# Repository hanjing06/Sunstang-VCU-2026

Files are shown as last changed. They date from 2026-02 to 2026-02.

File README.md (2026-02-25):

# Sunstang VCU 2026  
Vehicle Control Unit PCB for Western Sunstang

---

## Overview

The **Sunstang VCU 2026** is a custom-designed Vehicle Control Unit PCB developed in **KiCad v6+**.

The board integrates driver inputs, high-voltage enable logic, lighting control, safety interlocks, and vehicle state management into a centralized low-voltage control system.

The system is built around the **STM32 Nucleo-F302R8** development board (ARM Cortex-M4, 3.3V logic).

This PCB acts as the hardware interface between the microcontroller and the vehicle’s 12V automotive systems.

---

## System Architecture

The VCU operates across two voltage domains:

| Domain | Voltage | Description |
|---|---|---|
| Logic Domain | 3.3V | STM32 microcontroller logic |
| Automotive LV Domain | 12V | Switches, contactors, lighting, HV control |

Signal conditioning ensures safe interfacing between 12V automotive signals and 3.3V MCU GPIO/ADC inputs.

---

### System Integration Diagram

The diagram below shows the high-level integration of:

- STM32 Nucleo-F302R8 (3.3V logic domain)
- 12V automotive domain subsystems
- Pre-charge & contactor control
- Driver interface
- Lighting systems
- BMS interface

<p align="center">
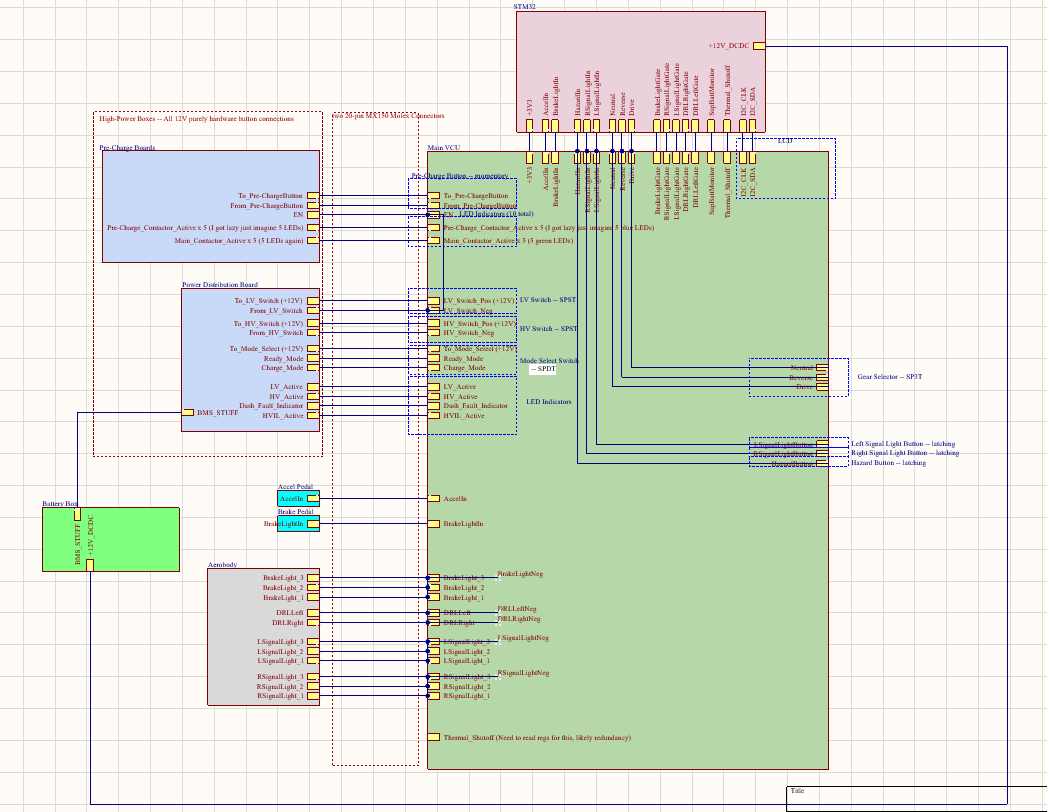
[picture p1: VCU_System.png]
  
</p>

---

## Microcontroller

**Board:** STM32 Nucleo-F302R8  
**Core:** ARM Cortex-M4  
**Logic Voltage:** 3.3V  

Primary functions:
- ADC acquisition (accelerator and brake pedals)
- Digital input processing (switches and selectors)
- Digital output control (contactors, LEDs, lighting)
- Vehicle state logic (ready mode, charge mode, HV enable)

Documentation:  
https://www.st.com/en/evaluation-tools/nucleo-f302r8.html

---

## Functional Responsibilities

The VCU manages the following subsystems:

### 1. Power & HV Control
- LV switch interface (12V)
- HV switch interface (12V)
- Pre-charge button input
- Pre-charge contactor feedback
- Main contactor feedback
- HV active indication
- BMS interface signals

### 2. Driver Inputs
- Accelerator pedal (ADC input)
- Brake pedal (ADC/digital input)
- Brake light trigger output

### 3. Mode Control
- Ready mode switch
- Charge mode switch
- Mode select (SPDT)
- Gear selector (SPST)

### 4. Lighting Control
- Brake lights
- Daytime running lights (DRL)
- Left turn signal
- Right turn signal
- Hazard (latching)
- Rear signal outputs

### 5. Safety Inputs
- HV active confirmation
- Thermal shutdown input (redundancy planned)
- Pre-charge verification before main contactor closure

---

## Startup Sequence (Simplified)

1. LV switch enabled  
2. HV switch engaged  
3. Pre-charge initiated  
4. Pre-charge confirmed  
5. Main contactor closed  
6. HV active verified  
7. Ready mode enabled  
8. Vehicle operational  

---

## Electrical Characteristics

| Parameter | Value |
|---|---|
| Automotive LV Input | 12V DC |
| MCU Logic Voltage | 3.3V |
| Microcontroller | STM32F302R8 |
| Design Tool | KiCad v6+ |

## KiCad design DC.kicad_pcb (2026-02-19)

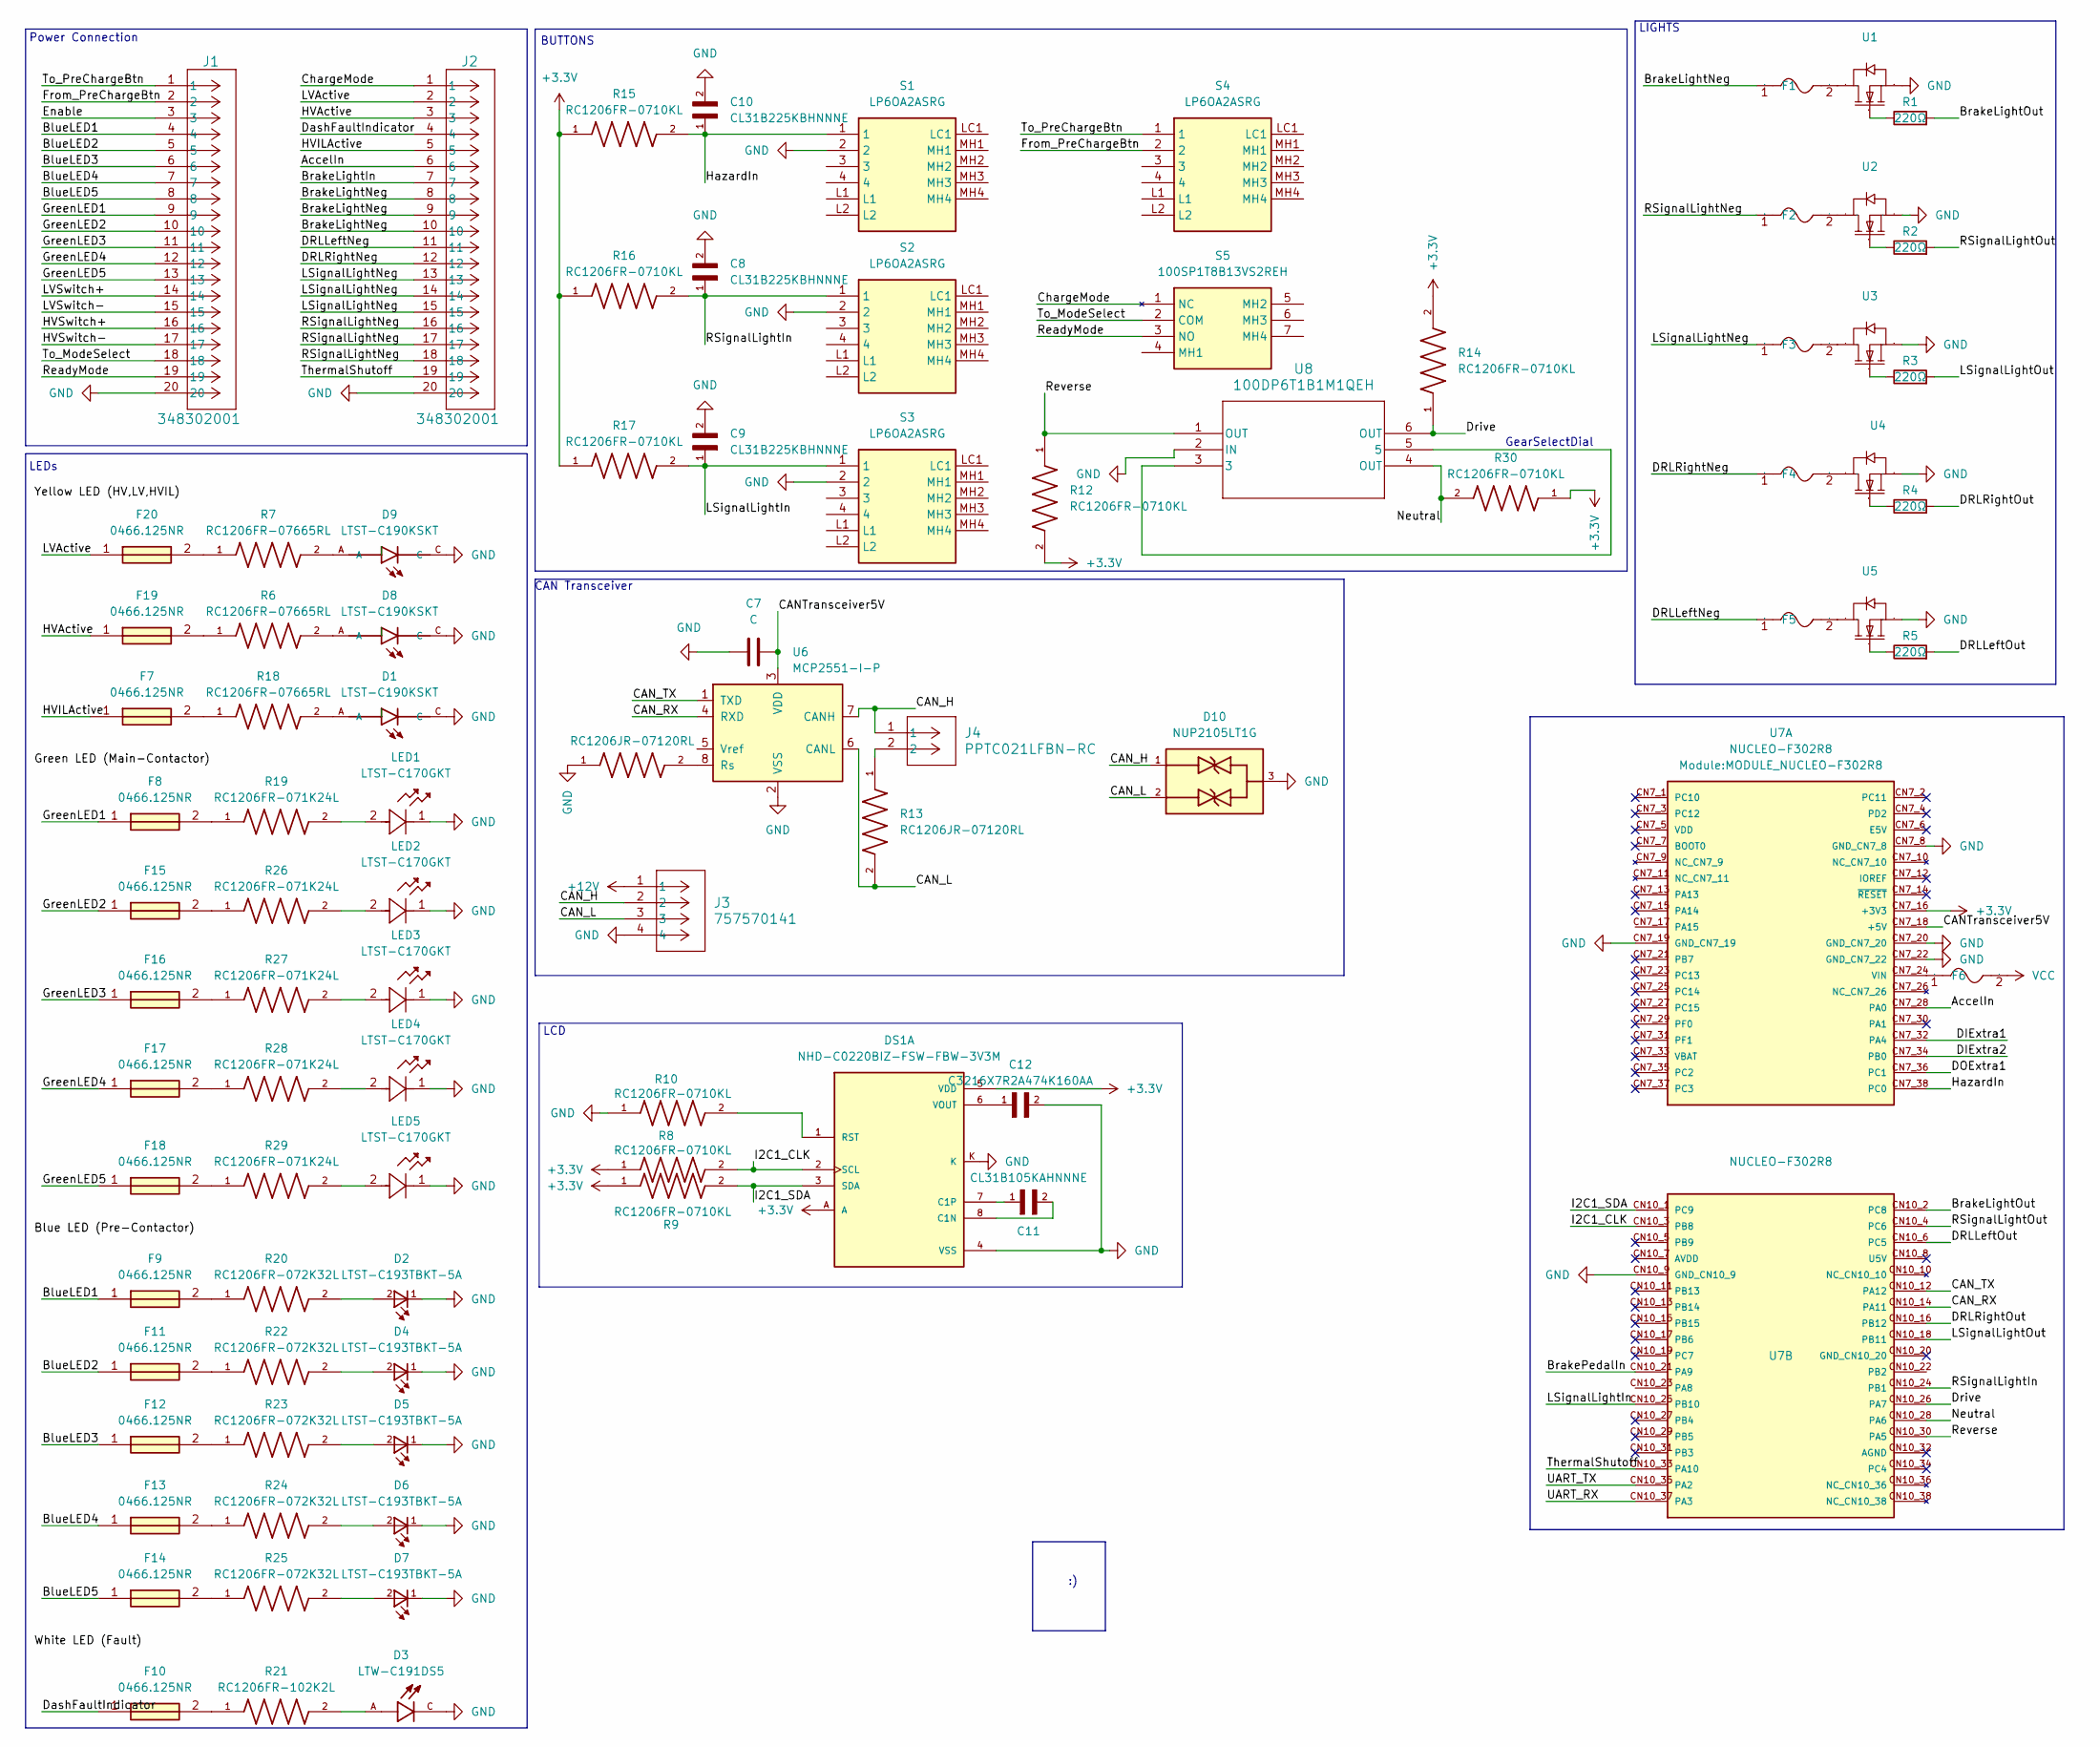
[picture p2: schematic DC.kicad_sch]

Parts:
C7: C; CAP-TH_L6.0-W3.5-P7.50-D1.0
C8, C9, C10: CL31B225KBHNNNE; CAPC3216X180N
C11: CL31B105KAHNNNE; CAPC3216X180N
C12: C3216X7R2A474K160AA; CAPC3216X180N
D1, D8, D9: LTST-C190KSKT; LEDM1608X80
D2, D4, D5, D6, D7: LTST-C193TBKT-5A; Fuse_0603_1608Metric
D3: LTW-C191DS5; LEDC1608X65N
D10: NUP2105LT1G; SOT95P237X111-3N; PARTREV 10
DS1: NHD-C0220BIZ-FSW-FBW-3V3M; LCD_NHD-C0220BIZ-FSW-FBW-3V3M; PARTREV 1.0
F1, F2, F3, F6: FUSE-TH_BD5.4-W22.5-P27.5-D0.8; Manufacturer Part 0001.2511.TR; LCSC Part Name 250V
F4, F5: FUSC3215X66N; Manufacturer Part 0001.2511.TR; LCSC Part Name 250V
F7, F8, F9, F10, F11, F12, F13, F14, F15, F16, F17, F18, F19, F20: 0466.125NR; FUSC3215X66N; Mouser Part Number 576-0466.125NR
J1, J2: 348302001; CONN_SD-34829-001_20_ST_MOL
J3: 757570141; CONN_SD-75757-010_1X4_F11p20_MOL
J4: PPTC021LFBN-RC; CONN2_LFBN-RC_SUL
LED1, LED2, LED3, LED4, LED5: LTST-C170GKT; LED_LTST-C170GKT_LTO
R1, R2, R3, R4, R5: 220Ω; RESC3216X70N
R6, R7, R18: RC1206FR-07665RL; RESC3116X65N
R8, R9, R10, R12, R14, R15, R16, R17, R30: RC1206FR-0710KL; RESC3116X65N
R11, R13: RC1206JR-07120RL; RESC3116X65N
R19, R26, R27, R28, R29: RC1206FR-071K24L; RESC3116X65N
R20, R22, R23, R24, R25: RC1206FR-072K32L; RESC3116X65N
R21: RC1206FR-102K2L; RESC3116X65N; PARTREV 12
S1, S2, S3, S4: LP6OA2ASRG; Mouser Part Number 612-LP6OA2ASRG
S5: 100SP1T8B13VS2REH; Manufacturer_Part_Number 100SP1T8B13VS2REH
U1, U2, U3, U4, U5: TO254P470X1016X2019-3P; Manufacturer Part FQP30N06L; LCSC Part Name 1个N沟道 耐压:60V 电流:32A 停产
U6: MCP2551-I-P; DIP-8_W7.62mm
U7: NUCLEO-F302R8; MODULE_NUCLEO-F302R8; PARTREV 17
U8: 100DP6T1B1M1QEH; TO_1M1QEH_EWI

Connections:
+3.3V: DS1.5 (VDD), DS1.A, R8.1, R9.1, R12.2, R14.2, R15.1, R16.1, R17.1, R30.1, U7.CN7_16 (+3V3)
+12V: J3.1
/AccelIn: J2.6, U7.CN7_28 (PA0)
/BlueLED1: F9.1, J1.4
/BlueLED2: F11.1, J1.5
/BlueLED3: F12.1, J1.6
/BlueLED4: F13.1, J1.7
/BlueLED5: F14.1, J1.8
/BrakeLightIn: J2.7
/BrakeLightNeg: F1.1, J2.8, J2.9, J2.10
/BrakeLightOut: R1.2, U7.CN10_2 (PC8)
/BrakePedalIn: U7.CN10_21 (PA9)
/CANTransceiver5V: C7.2, U6.3 (VDD), U7.CN7_18 (+5V)
/CAN_H: D10.1, J3.2, J4.1, U6.7 (CANH)
/CAN_L: D10.2, J3.3, R13.2, U6.6 (CANL)
/CAN_RX: U6.4 (RXD), U7.CN10_14 (PA11)
/CAN_TX: U6.1 (TXD), U7.CN10_12 (PA12)
/ChargeMode: J2.1, S5.1 (NC)
/DIExtra1: U7.CN7_32 (PA4)
/DIExtra2: U7.CN7_34 (PB0)
/DOExtra1: U7.CN7_36 (PC1)
/DRLLeftNeg: F5.1, J2.11
/DRLLeftOut: R5.2, U7.CN10_6 (PC5)
/DRLRightNeg: F4.1, J2.12
/DRLRightOut: R4.2, U7.CN10_16 (PB12)
/DashFaultIndicator: F10.1, J2.4
/Drive: R14.1, U7.CN10_26 (PA7), U8.6 (OUT)
/Enable: J1.3
/From_PreChargeBtn: J1.2, S4.2
/GreenLED1: F8.1, J1.9
/GreenLED2: F15.1, J1.10
/GreenLED3: F16.1, J1.11
/GreenLED4: F17.1, J1.12
/GreenLED5: F18.1, J1.13
/HVActive: F19.1, J2.3
/HVILActive: F7.1, J2.5
/HVSwitch+: J1.16
/HVSwitch-: J1.17
/HazardIn: C10.1, R15.2, S1.1, U7.CN7_38 (PC0)
/I2C1_CLK: DS1.2 (SCL), R8.2, U7.CN10_3 (PB8)
/I2C1_SDA: DS1.3 (SDA), R9.2, U7.CN10_1 (PC9)
/LSignalLightIn: C9.1, R17.2, S3.1, U7.CN10_25 (PB10)
/LSignalLightNeg: F3.1, J2.13, J2.14, J2.15
/LSignalLightOut: R3.2, U7.CN10_18 (PB11)
/LVActive: F20.1, J2.2
/LVSwitch+: J1.14
/LVSwitch-: J1.15
/Neutral: R30.2, U7.CN10_28 (PA6), U8.4 (OUT)
/RSignalLightIn: C8.1, R16.2, S2.1, U7.CN10_24 (PB1)
/RSignalLightNeg: F2.1, J2.16, J2.17, J2.18
/RSignalLightOut: R2.2, U7.CN10_4 (PC6)
/ReadyMode: J1.19, S5.3 (NO)
/Reverse: R12.1, U7.CN10_30 (PA5), U8.1 (OUT)
/ThermalShutoff: J2.19, U7.CN10_33 (PA10)
/To_ModeSelect: J1.18, S5.2 (COM)
/To_PreChargeBtn: J1.1, S4.1
/UART_RX: U7.CN10_37 (PA3)
/UART_TX: U7.CN10_35 (PA2)
GND: C7.1, C8.2, C9.2, C10.2, C12.2, D1.C, D2.1, D3.C, D4.1, D5.1, D6.1, D7.1, D8.C, D9.C, D10.3, DS1.4 (VSS), DS1.K, J1.20, J2.20, J3.4, LED1.1, LED2.1, LED3.1, LED4.1, LED5.1, R10.1, R11.1, S1.2, S2.2, S3.2, U1.3 (S), U2.3 (S), U3.3 (S), U4.3 (S), U5.3 (S), U6.2 (VSS), U7.CN7_8 (GND_CN7_8), U7.CN7_19 (GND_CN7_19), U7.CN7_20 (GND_CN7_20), U7.CN7_22 (GND_CN7_22), U7.CN10_9 (GND_CN10_9), U8.2 (IN)
unnamed: D1.A, R18.2
unnamed: D2.2, R20.2
unnamed: D3.A, R21.2
unnamed: D4.2, R22.2
unnamed: D5.2, R23.2
unnamed: D6.2, R24.2
unnamed: D7.2, R25.2
unnamed: D8.A, R6.2
unnamed: D9.A, R7.2
unnamed: C11.2, DS1.8 (C1N)
unnamed: C11.1, DS1.7 (C1P)
unnamed: DS1.1 (RST), R10.2
unnamed: C12.1, DS1.6 (VOUT)
unnamed: F7.2, R18.1
unnamed: F8.2, R19.1
unnamed: F9.2, R20.1
unnamed: F10.2, R21.1
unnamed: F11.2, R22.1
unnamed: F12.2, R23.1
unnamed: F13.2, R24.1
unnamed: F14.2, R25.1
unnamed: F15.2, R26.1
unnamed: F16.2, R27.1
unnamed: F17.2, R28.1
unnamed: F18.2, R29.1
unnamed: F19.2, R6.1
unnamed: F20.2, R7.1
unnamed: J4.2, R13.1
unnamed: LED1.2, R19.2
unnamed: LED2.2, R26.2
unnamed: LED3.2, R27.2
unnamed: LED4.2, R28.2
unnamed: LED5.2, R29.2
unnamed: F1.2, U1.2 (D)
unnamed: R1.1, U1.1 (G)
unnamed: F2.2, U2.2 (D)
unnamed: R2.1, U2.1 (G)
unnamed: F3.2, U3.2 (D)
unnamed: R3.1, U3.1 (G)
unnamed: F4.2, U4.2 (D)
unnamed: R4.1, U4.1 (G)
unnamed: F5.2, U5.2 (D)
unnamed: R5.1, U5.1 (G)
unnamed: R11.2, U6.8 (Rs)
unnamed: F6.1, U7.CN7_24 (VIN)
unnamed: U8.3, U8.5

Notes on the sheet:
Power Connection
CAN Transceiver
BUTTONS
GearSelectDial
LIGHTS
LCD
LEDs

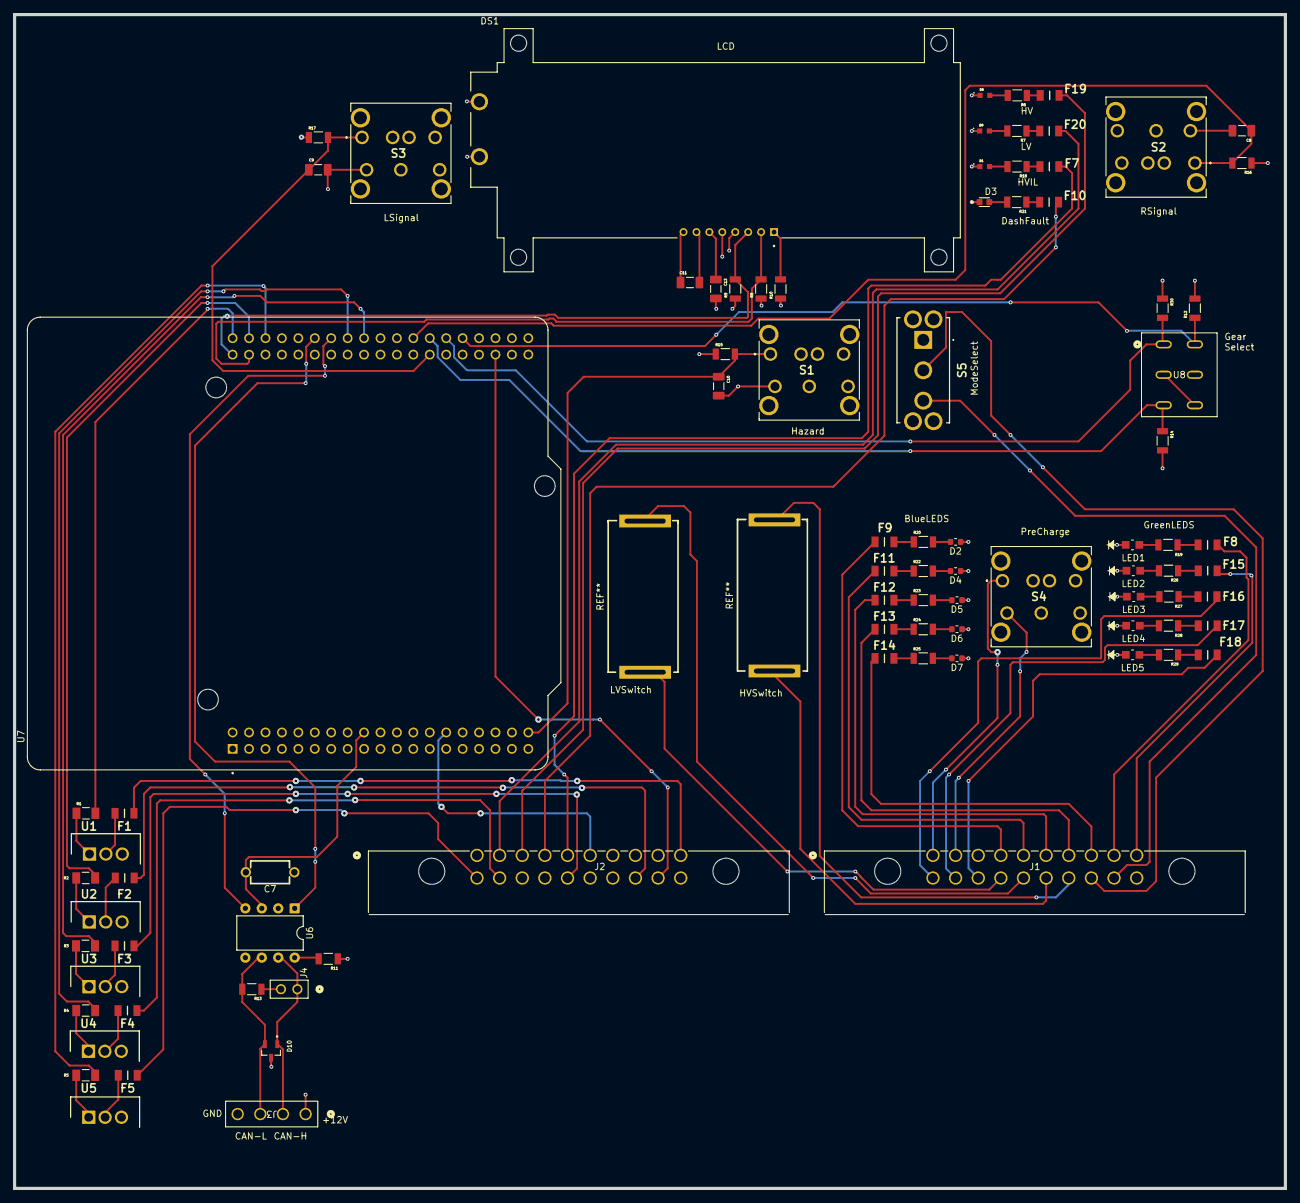
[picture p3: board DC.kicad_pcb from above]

Board: 4 copper layers, 196.5 x 181.5 mm, 88 parts (0 on the bottom side), 90 nets.

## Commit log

2026-02-11 Updated LEDs, buttons and power distribution headers
    [DC.kicad_sch]
2026-02-11 Imported footprints
    [DC.kicad_pcb]
2026-02-11 AccelIn to adc and I2C connection
    [DC.kicad_sch]
2026-02-11 Deleted buttons!
    [DC.kicad_sch]
2026-02-11 Added LCD!
    [DC.kicad_sch]
2026-02-11 Symbols all have a footprint and LCD added
    [DC.kicad_pcb, DC.kicad_sch]
2026-02-13 Fixed airwires and CANtransceiver, added mode select switch
    [DC.kicad_sch]
2026-02-13 LEDs routed
    [DC.kicad_pcb]
2026-02-13 Added HV and LV switches
    [DC.kicad_pcb]
2026-02-16 Routed front and back
    [DC.kicad_pcb]
2026-02-16 Updated symbols/footprints
    [DC.kicad_sch]
2026-02-16 Change molex orientation
    [DC.kicad_pcb]
2026-02-16 3v3 power
    [DC.kicad_sch]
2026-02-18 Added gear-select, needs to be wired
    [DC.kicad_pcb, DC.kicad_sch]
2026-02-19 Updated pcb with new routing and gear select. Still errors to correct
    [DC.kicad_pcb, DC.kicad_sch]
